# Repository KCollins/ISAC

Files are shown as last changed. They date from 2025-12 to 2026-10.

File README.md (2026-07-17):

# ISAC
The In-Situ Autonomous Column (ISAC) is a low-cost drifter and sensor platform designed to characterize sinking particles in the surface of aquatic environments.

### [**Click here to read the documentation page.**](https://kcollins.github.io/ISAC)

ISAC is both an observational instrument and an experimental instrument. The ISAC drifter monitors the sinking of particulate matter (e.g., volcanic ash, biological cells/aggregates) through the surface. Passive sensing of the sinking particle field (by backscatter and chlorophyll-a fluorescence optical sensors) and active sampling of seawater for biogeochemical variables allows users of ISAC to test the effects of nutrient supply on phytoplankton populations, survey across biogeochemical gradients (in time and space), experimentally manipulate the particle field, and assess sinking speeds of particulate matter and their contribution to the carbon cycle. These capabilities make ISAC a novel tool for interrogating biogeochemistry in aquatic environments.

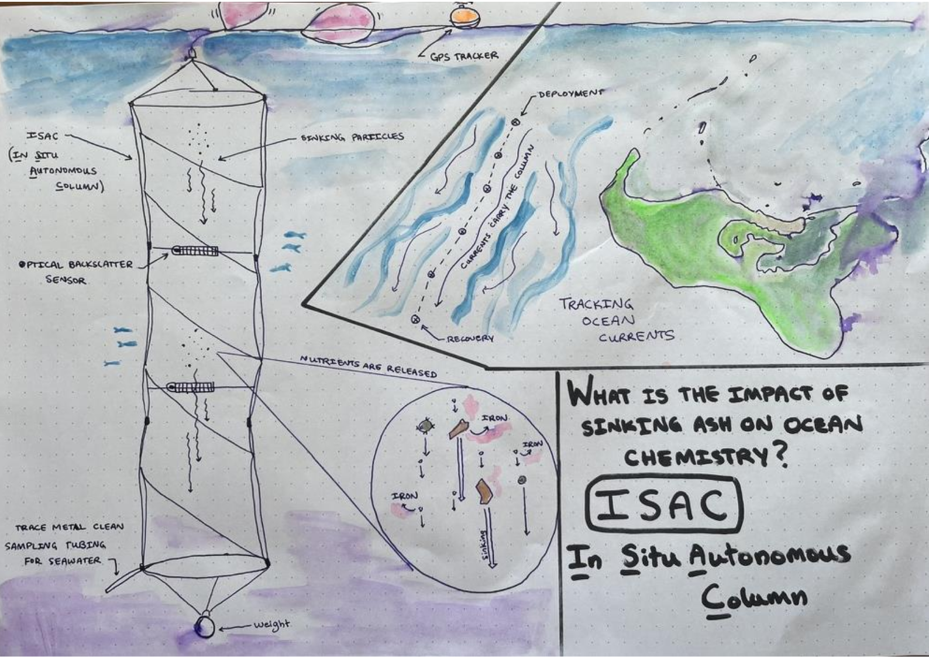
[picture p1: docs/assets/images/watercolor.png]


An initial ISAC prototype was successfully built and deployed in the Western Tropical South Pacific (WTSP) in March 2026. This prototype consists of a nylon column drogue five meters in length, suspended between a float at the top and a weight at the bottom. The column is hand-deployable, has a low above water profile, and drifts with the water parcel. The length of the column is equipped with vertically distributed [Optical Backscatter Sensors (OBS)](https://github.com/tedlanghorst/OpenOBS-328) which monitor sinking particulate matter by logging time series of seawater turbidity over the course of deployment. Ash or other particulate material is deposited manually at the top of the column and observed by the sensors as it settles over the course of 24 hours or more. At the end of the deployment, water samples are pumped from the bottom of the column and the column and sensors are recovered. Initial experiments demonstrated ISAC’s ability to sense ambient and experimental particle fields. Crucially, its ability to sample for trace metal nutrients without contamination was [verified on discrete seawater samples](https://doi.org/10.5281/zenodo.21253933). 

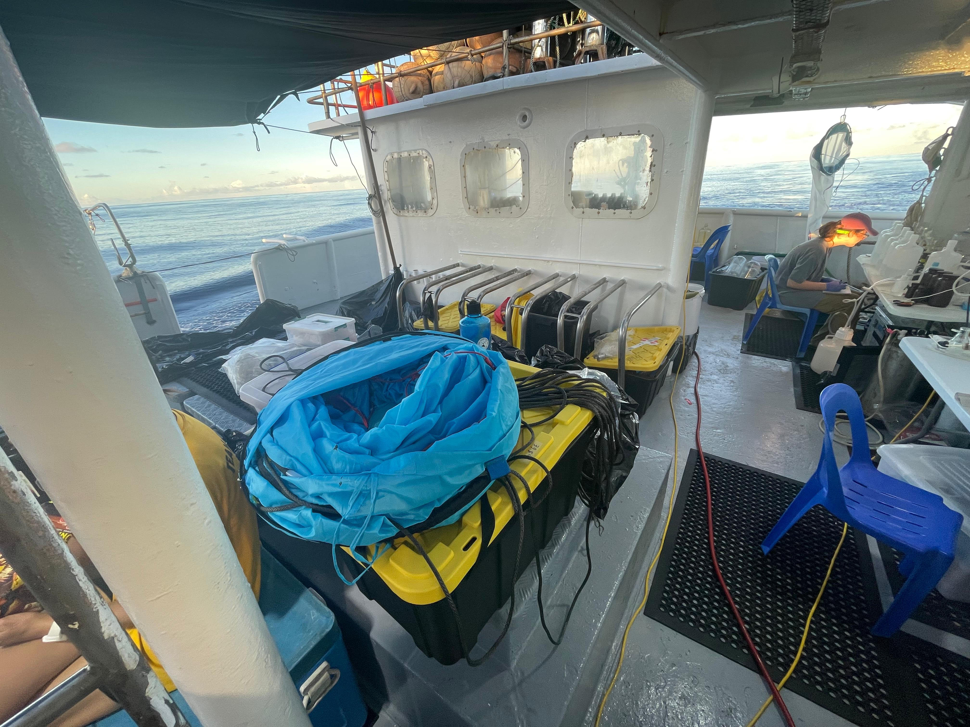
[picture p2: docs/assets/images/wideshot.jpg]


ISAC is also adaptable to a range of other science questions in both lake and marine environments, and closes gaps in the observational system. Moored instrumentation requires routine maintenance and lacks the ability to track moving parcels of water. Uncrewed vehicles require a pilot and shipboard support and skill for deployment and operation. As a water-following device, ISAC is intended to be used where measurements are required to resolve the spatial and temporal evolution of particles and water masses. Proximal to both the ocean and lakes, wildfires are becoming frequent and their impacts on aquatic ecosystems have been understudied. Harmful algae blooms (HABS), which present a challenge for coastal resilience and protection of fisheries, result from an unknown causal chain in changing water chemistry. In response to natural or anthropogenic disturbance events such as volcanic eruptions, wildfires, and HABs, ISAC is an ideal deployable instrument type for mission-oriented experiments and water monitoring. Understanding the fate of particulate matter and its impact on the ecosystem will inform both basic science and the needs of monitoring research and regulatory programs.

### Principal Investigators
 * [Kiefer Forsch](https://orcid.org/0000-0003-1076-164X), University of Southern California
 * [Kristina Collins](https://orcid.org/0000-0002-3816-1948), Space Science Institute

### Manufacturing Collaborators
 * [Ben Kaufman](https://orcid.org/0009-0005-3339-7686): 3D printing, design support
 * [Mike Hawley](https://orcid.org/0009-0007-5088-750X): Sewing

### Acknowledgments
Seed funding for this project was provided by [Growing Oceans](www.growingoceans.com). 
<!--
Sewing consultation was provided by [Capital Quilts](https://www.capitalquilts.com). Collaborative opportunities were supported by AGU LANDiNG and [3D Music](https://3dmusic.org/). Our muse is [Oreo the Cat](https://github.com/KCollins/ISAC/blob/main/docs/assets/images/Oreo.jpg). 
!-->

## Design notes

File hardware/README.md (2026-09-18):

This directory contains hardware source files.

### OpenOBS Sensor Heads
These are all designed to use with Adafruit carrier boards. They do not include any spots for a pressure board, since for our application we're only interested in backscatter.
 - **SensorCapV11.stl**: Suitable for the [VCNL4010](https://www.adafruit.com/product/466?srsltid=AU7gw4UTuG5I8HEObkcyDNkkXtAUzCGb80vCChXrD3bDop7IK6JsJFDD), which is the board used (and validated) in Ted Langhorst's original design.
 - **SensorCapV17.stl**: Suitable for the VCNL4020, 4030, 4040.

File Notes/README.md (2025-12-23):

## Design Notes

### Design Requirements
**Materials:** ABS, PLA, polycarbonate. Aluminum, stainless, Ti. Can't use Fe (obviously), copper, brass or bronze. For lines, assume Dyneema.

## Mechanical Design
Initial sketches.




## Electronics and Instrumentation
### OBS Sensor
Current plan: OpenOBS 328. https://github.com/tedlanghorst/OpenOBS-328

### Peristaltic Pump
Looking at this one: https://www.hardware-x.com/article/S2468-0672(20)30024-9/fulltext

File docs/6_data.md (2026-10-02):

---
layout: page
title: Data
permalink: /data/
---

## Table of Contents 
{:.no_toc}
* TOC
{:toc}

## Processing Code
See https://www.github.com/kcollins/ISAC for Jupyter notebooks with processing code. 

## Deployments

| **Cruise** | **Dates** | **Vessel** | **ISAC Version Description** | **Deployment Goals** | **Datasets** | **Analysis** | 
|---|---|---|---|---|---|---|
| PACSUN2603 | March 2026 | [*F/V Pacific Sunrise*](https://vessels.wcpfc.int/vessel/4073)|  Drogue with 2 OpenOBS sensors.  |  Drogue test, initial ash experiment. | |  
| PACSUN2611 |  November 2026  | | Drogue with 5 OpenOBS sensors. | | | | 

## Visualizations
We use [OpenSpace](www.openspaceproject.com) to create integrated ISAC visualizations. Code, instructions and demo videos can be found here: 
<iframe width="700" height="750" src="https://www.youtube.com/embed/Si8AKwayehU?list=PLTvFnCylkeSBzXo7BVH0SzxiXEjGLZG2X" title="ISAC2, ISAC3, Volcano 1" frameborder="0" allow="accelerometer; autoplay; clipboard-write; encrypted-media; gyroscope; picture-in-picture; web-share" referrerpolicy="strict-origin-when-cross-origin" allowfullscreen></iframe>

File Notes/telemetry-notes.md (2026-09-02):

# Telemetry development notes

## Parts 
- Feather M0 w/ 900 MHz LoRa

## Feather setup
 - [X] Install libraries per instructions at https://learn.adafruit.com/adafruit-feather-m0-basic-proto/using-with-arduino-ide
 - [X] Test blink sketch
 - [ ] Test TX and RX sketches

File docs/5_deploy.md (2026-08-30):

---
layout: page
title: Deployment Protocol
permalink: /deploy/
---

## Introduction
{:.no_toc}

This page contains deployment protocols. 

*Like ISAC, this page is a work in progress.*

## Table of Contents 
{:.no_toc}
* TOC
{:toc}

## Packing Checklist
### Tools for Drogue
- [ ] Line (Dyneema recommended)
- [ ] ***(3D printed blocks?)***
### Tools for OBS sensors
- [ ] USB to micro-USB cable
- [ ] USB-A to USB-C cable
- [ ] 3.6V battery in AA form factor, one for each sensor (bring extras)
- [ ] micro SD card, one for each sensor
- [ ] micro SD card reader
- [ ] charger for 3.6V batteries
- [ ] crescent wrench (if using automotive plugs)
- [ ] strap wrench

## Sensor Checklist
- [ ] Remove cap with strap wrench
- [ ] Check battery voltage
- [ ] Connect to computer via USB
- [ ] Program OpenOBS.ino
- [ ] Replace cap, tighten with strap wrench
- [ ] Record sensor ID. column placement, and time

## Drogue Deployment Protocol
### Deployment
Fllowing a recently “pinged” location (lat/lon) of the ISAC instrumentation, the drifter is hand-deployed over the side of the vessel at a nominal 1 knot speed forward. The float is deployed first and using the slow drift forward and drag on the float, the column is extended at the surface and finally, the weight is dropped into the water, which sinks and orients the column vertically.
The position of the device is nominally tracked every 15 minutes over the entire deployment period (up to 24 hrs). 

### Water Sampling
Water sampling is conducted with a diaphragm pump.

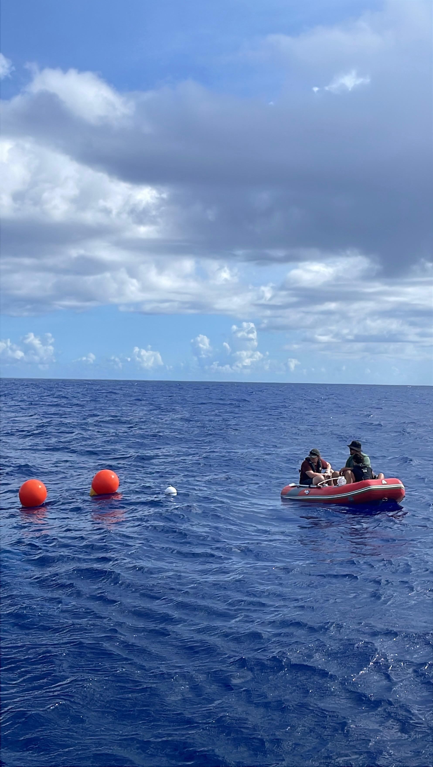
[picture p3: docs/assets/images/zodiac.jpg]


### Recovery
Upon recovery, the vessel must use a grappling hook attached to a line to grab the float and pull it up onto the boat, careful to keep the drifter components away from the side of the vessel. 

---

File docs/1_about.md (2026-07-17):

---
layout: page
title: About
permalink: /about/
mermaid: true
---

The In-Situ Autonomous Column (ISAC) is a low-cost drifter and sensor platform designed to characterize sinking particles in the surface of aquatic environments. 

**ISAC is currently under development.** For a list of deployments to date, see the "Data" page in the menu above.

## About ISAC

The In Situ Autonomous Column (ISAC) is a low-cost system designed to observe sinking ash in seawater. The movement of particulate matter in aquatic ecosystems is intimately tied to the global cycling of carbon and nutrients, and to ecosystem productivity. The fate of particulate matter in the surface (e.g., phytoplankton, ash) is controlled by how quickly it sinks, yet the behavior of these particles is not well-understood, as it is difficult to measure in a natural environment and not possible to reproduce in a lab.  ISAC offers an inexpensive platform for investigating fundamental science questions of particle dynamics and biogeochemical processes under natural oceanographic conditions. 

An initial ISAC prototype was successfully built and deployed in the Western Tropical South Pacific (WTSP) in March 2026. This prototype consists of a nylon column drogue five meters in length, suspended between a float at the top and a weight at the bottom. The column is hand-deployable, has a low above water profile, and drifts with the water parcel. The length of the column is equipped with vertically distributed Optical Backscatter Sensors (OBS) which monitor sinking particulate matter by logging time series of seawater turbidity over the course of deployment. Ash or other particulate material is deposited manually at the top of the column and observed by the sensors as it settles over the course of 24 hours or more. At the end of the deployment, water samples are pumped from the bottom of the column and the column and sensors are recovered. Initial experiments demonstrated ISAC’s ability to sense ambient and experimental particle fields. Crucially, its ability to sample for trace metal nutrients without contamination was [verified on discrete seawater samples](https://doi.org/10.5281/zenodo.21253933). 

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

## Planned Improvements
We are in the process of improving ISAC’s technology readiness level in four domains: structural components, including the drogue column and float; electronic components, including power and telemetry; electromechanical components, including automated ash dispersal and water sampling; and optical sensors, including particle backscatter and chlorophyll-a fluorescence. Since ISAC is a modular system, not every column needs to be equipped with all components; a subset may be selected depending on the science question being addressed. We envision a fully equipped column which will be capable of transmitting position and sensor data in real time, as well as automatically handling the mechanical tasks of water sampling and scattering particulate matter at the top of the column.  

The subsystems we plan to develop are shown in the dependency chart below. 

```mermaid
---
title: ISAC Dependency Graph
---
%%{
  init: {
    'flowchart': {
      'nodeSpacing': 10,
      'rankSpacing': 15,
      'useMaxWidth': false
    }
  }
}%%

flowchart LR
    %% Sensors grouped at the bottom, pointing up to the Drogue
    subgraph Sensors [Environmental Sensors]
        G(Optical Backscatter)
        H(Chlorophyll A)
    end

    %% Core Components
    subgraph Structural [Structural Components]
        A(Column Drogue)
        B(Float)
    end

    subgraph Electronic [Electronic Subsystems]
        C(Power Bus)
        D(Telemetry)
    end

    subgraph Electromechanical [Electromechanical Subsystems]
        E(Automated Water Sampling)
        F(Automated Ash Dispersal)
    end

    %% System Hierarchy and Flow
    %% B-->A
    E -->A
    E --> C
    E --> D
    E --> B

    F --> C
    F --> D

    D --> C
    D --> B
    C --> B

    %% Connecting Sensors to Drogue
    H --> A
    G --> A

    %% %% Invisible structural links to keep layout clean and prevent overlap
    B ~~~ A
    H ~~~ G
    style Structural fill:#dcfce7,stroke:#16a34a,stroke-width:2px
    style Electromechanical fill:#fee2e2,stroke:#dc2626,stroke-width:2px
    style Electronic fill:#ADD8E6,stroke:#0116ff,stroke-width:2px
    %% style Sensors fill:#FFFFED,stroke:#dc2676,stroke-width:2px
```

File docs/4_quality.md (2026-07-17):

---
layout: page
title: Quality, Calibration and Test Procedures
permalink: /testing/
mermaid: true
---

This page concerns quality, calibration and test procedures for subsystems. 
*Like ISAC, this page is a work in progress.*

## OpenOBS Sensors
### QA/QC
Some of the quality issues we encountered with the OpenOBS sensors on our first deployment are reflected in the Ishikawa diagram below. 
```mermaid
ishikawa-beta
    OpenOBS-328 Failures
    Personnel
        Incomplete deployment protocol
    Machines
        Printer settings
        Epoxy protocol
    Materials
        Sensor heads
            Use of PLA (should be using PETG)
        Sensor endcaps
            Automotive cap leaks (should use threaded inserts)
    Methods
        Uneven PVC cuts
            Should brace PVC to ensure even cuts
        Uneven mating of sensor heads
            Should tape around sensor head
    Measurements
        Uncalibrated sensors
    Environment
        Saltwater infiltration     
```

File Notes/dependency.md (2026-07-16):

```mermaid
---
title: ISAC Dependency Graph
---
flowchart LR
    %% Subgraphs
    subgraph Electromechanical [Electromechanical Subsystems]
        E(Automated Water Sampling System)
        F(Automated Ash Dispersal System)
    end

    subgraph Electronic [Electronic Subsystems]
        D(Telemetry System)
        C(Power Bus)
    end

    subgraph Structural [Structural Components]
        B(Float)
        A(Column Drogue)
    end

    subgraph Sensors [Sensors]
        H(Chlorophyll A)
        G(Backscatter)
    end

    %% Bundled Connections
    E --> A & B & C & D
    F --> C & D
    D --> C & B
    C --> B
    G --> A
    H --> D

    %% Color & Border Styles
    style Structural fill:#dcfce7,stroke:#16a34a,stroke-width:2px
    style Electromechanical fill:#fee2e2,stroke:#dc2626,stroke-width:2px
    style Electronic fill:#ADD8E6,stroke:#0116ff,stroke-width:2px
    style Sensors fill:#fffde6,stroke:#FFDB58,stroke-width:2px

    %% Subgraph Title Font Scaling
    style Electromechanical font-size:16px,font-weight:bold
    style Electronic font-size:16px,font-weight:bold
    style Structural font-size:16px,font-weight:bold
    style Sensors font-size:18px,font-weight:bold

    %% Universal Large Font Styling for Nodes
    classDef largeFont font-size:20px,font-weight:bold;
    class A,B,C,D,E,F,G,H largeFont;
```

```mermaid
---
title: ISAC Dependency Graph
---
flowchart LR
    %% Subgraphs
    subgraph Electromechanical [Electromechanical Subsystems]
        E(Automated Water Sampling System)
        F(Automated Ash Dispersal System)
    end

    subgraph Electronic [Electronic Subsystems]
        D(Telemetry System)
        C(Power Bus)
    end

    subgraph Structural [Structural Components]
        B(Float)
        A(Column Drogue)
    end

    subgraph Sensors [Environmental Sensors]
        H(Chlorophyll A)
        G(Backscatter)
    end

    %% Connections
    E --> A
    E --> B
    E --> C
    E --> D

    F --> C
    F --> D

    D --> C
    D --> B
    C --> B

    G --> A
    H --> D

    %% Style Definitions
    style Structural fill:#dcfce7,stroke:#16a34a,stroke-width:2px
    style Electromechanical fill:#fee2e2,stroke:#dc2626,stroke-width:2px
    style Electronic fill:#ADD8E6,stroke:#0116ff,stroke-width:2px
    style Sensors fill:#fffde6,stroke:#FFDB58,stroke-width:2px
```

```mermaid
---
title: ISAC Dependency Graph
---
flowchart LR
    %% Subgraphs
    subgraph Electromechanical [Electromechanical Subsystems]
        E(Automated Water <br>Sampling System)
        F(Automated Ash <br>Dispersal System)
    end

    subgraph Electronic [Electronic Subsystems]
        D(Telemetry System)
        C(Power Bus)
    end

    subgraph Structural [Structural Components]
        B(Float)
        A(Column Drogue)
    end

    subgraph Sensors [Environmental Sensors]
        H(Chlorophyll A)
        G(Backscatter)

    end

    %% --- Streamlined Connections ---
    
    %% Electromechanical Layer
    E --> A
    E --> B
    E --> C
    E --> D

    F --> C
    F --> D

    %% Electronic Layer
    D --> C
    D --> B
    C --> B

    %% Sensors Layer
    G --> A
    H --> D

    %% Style Definitions
    style Structural fill:#dcfce7,stroke:#16a34a,stroke-width:2px
    style Electromechanical fill:#fee2e2,stroke:#dc2626,stroke-width:2px
    style Electronic fill:#ADD8E6,stroke:#0116ff,stroke-width:2px
    style Sensors fill:#fffde6,stroke:#FFDB58,stroke-width:2px
```

```mermaid
---
title: ISAC Dependency Graph
---

flowchart LR
    %% Sensors grouped at the bottom, pointing up to the Drogue
    subgraph Sensors [Environmental Sensors]
        G(Optical Backscatter Sensor)
        H(Chlorophyll A Sensor)
    end

    %% Core Components
    subgraph Structural [Structural Components]
        A(Column Drogue)
        B(Float)
    end

    subgraph Electronic [Electronic Subsystems]
        C(Power Bus)
        D(Telemetry System)
    end

    subgraph Electromechanical [Electromechanical Subsystems]
        E(Automated Water Sampling System)
        F(Automated Ash Dispersal System)
    end

    %% System Hierarchy and Flow
    %% B-->A
    E -->A
    E --> C
    E --> D
    E --> B

    F --> C
    F --> D

    D --> C
    D --> B
    C --> B

    %% Connecting Sensors to Drogue
    H --> A
    G --> A

    %% %% Invisible structural links to keep layout clean and prevent overlap
    B ~~~ A
    G ~~~ Sensors
    style Structural fill:#dcfce7,stroke:#16a34a,stroke-width:2px
    style Electromechanical fill:#fee2e2,stroke:#dc2626,stroke-width:2px
    style Electronic fill:#ADD8E6,stroke:#0116ff,stroke-width:2px
    %% style Sensors fill:#FFFFED,stroke:#dc2676,stroke-width:2px
```

```mermaid
---
title: ISAC Dependency Graph
---
flowchart LR
    %% Subgraphs
    subgraph Electromechanical [Electromechanical Subsystems]
        E(Automated Water <br>Sampling System)
        F(Automated Ash <br>Dispersal System)
    end

    subgraph Electronic [Electronic Subsystems]
        D(Telemetry System)
        C(Power Bus)
    end

    subgraph Structural [Structural Components]
        B(Float)
        A(Column Drogue)
    end

    subgraph Sensors [Environmental Sensors]
        G(Optical <br>Backscatter)
        H(Chlorophyll A)
        I(Optical and Acoustic Sensors)
    end

    %% --- Streamlined Connections ---
    
    %% Electromechanical Layer
    E --> A
    E --> B
    E --> C
    E --> D

    F --> C
    F --> D

    %% Electronic Layer
    D --> C
    D --> B
    C --> B

    %% Sensors Layer
    G --> A
    H --> A
    I-->A

    %% Invisible vertical constraints to stack nodes vertically inside subgraphs
    E ~~~ F
    D ~~~ C
    A ~~~ B
    G ~~~ H

    %% Style Definitions
    style Structural fill:#dcfce7,stroke:#16a34a,stroke-width:2px
    style Electromechanical fill:#fee2e2,stroke:#dc2626,stroke-width:2px
    style Electronic fill:#ADD8E6,stroke:#0116ff,stroke-width:2px
    style Sensors fill:#fffde6,stroke:#FFDB58,stroke-width:2px
```

Compact version:
```mermaid
---
title: ISAC Dependency Graph
---
%%{
  init: {
    'flowchart': {
      'nodeSpacing': 10,
      'rankSpacing': 15,
      'useMaxWidth': false
    }
  }
}%%

flowchart LR
    %% Sensors grouped at the bottom, pointing up to the Drogue
    subgraph Sensors [Environmental Sensors]
        G(Optical Backscatter)
        H(Chlorophyll A)
    end

    %% Core Components
    subgraph Structural [Structural Components]
        A(Column Drogue)
        B(Float)
    end

    subgraph Electronic [Electronic Subsystems]
        C(Power Bus)
        D(Telemetry)
    end

    subgraph Electromechanical [Electromechanical Subsystems]
        E(Automated Water Sampling)
        F(Automated Ash Dispersal)
    end

    %% System Hierarchy and Flow
    %% B-->A
    E -->A
    E --> C
    E --> D
    E --> B

    F --> C
    F --> D

    D --> C
    D --> B
    C --> B

    %% Connecting Sensors to Drogue
    H --> A
    G --> A

    %% %% Invisible structural links to keep layout clean and prevent overlap
    B ~~~ A
    H ~~~ G
    style Structural fill:#dcfce7,stroke:#16a34a,stroke-width:2px
    style Electromechanical fill:#fee2e2,stroke:#dc2626,stroke-width:2px
    style Electronic fill:#ADD8E6,stroke:#0116ff,stroke-width:2px
    %% style Sensors fill:#FFFFED,stroke:#dc2676,stroke-width:2px
```

```mermaid
---
title: ISAC Dependency Graph
---
%%{
  init: {
    'flowchart': {
      'nodeSpacing': 10,
      'rankSpacing': 20,
      'useMaxWidth': false
    }
  }
}%%

flowchart LR
    %% Electromechanical (Left)
    subgraph Electromechanical [Electromechanical Subsystems]
        E(Automated Water Sampling)
        F(Automated Ash Dispersal)
    end

    %% Sensors (Bottom Left/Middle)
    subgraph Sensors [Environmental Sensors]
        G(Modular Sensors)
        H(Integrated Sensors)
    end

    %% Electronic (Middle/Top)
    subgraph Electronic [Electronic Subsystems]
        D(Telemetry)
        C(Power Bus)
    end

    %% Structural (Right)
    subgraph Structural [Structural Components]
        A(Column Drogue)
        B(Float)
    end

    %% System Hierarchy and Flow
    E --> A
    E --> C
    E --> D
    E --> B

    F --> C
    F --> D

    D --> C
    D --> B
    C --> B

    %% Connecting Sensors cleanly
    H --> D
    G --> A

    %% Invisible alignment constraints to keep subgraphs stacked perfectly
    E ~~~ G
    D ~~~ C
    B ~~~ A
    H ~~~ G
    
    %% Styling
    style Structural fill:#dcfce7,stroke:#16a34a,stroke-width:2px
    style Electromechanical fill:#fee2e2,stroke:#dc2626,stroke-width:2px
    style Electronic fill:#ADD8E6,stroke:#0116ff,stroke-width:2px
```

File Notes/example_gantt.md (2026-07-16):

```mermaid
gantt
    title All-Hands Science Timeline
    dateFormat  YYYY-MM-DD

section Natural Variables
    Nitrogen Fixation Annual Cycle: N, 2026-11-01, 150d
    Whale Season: whales, 2026-07-01, 90d

section Meetings and Conferences
    All-Hands Science Discussion: active, milestone, 2026-07-01, 1d
    All-Hands Science Data Forum: milestone, 2026-10-15, 1d
    AGU26, San Francisco: 2026-12-07, 5d

section Field Work
    November cruise (tentative): 2026-11-10, 10d
    January cruise: 2027-01-08, 10d
    March cruise: 2027-03-15, 10d

section Logistics and Milestones
    Thanksgiving 2026: milestone, 2026-11-26, 1d

section ISAC Team
    %% Logistics and Milestones (Include academic calendar and OOF notices; merge these into one logistics section when combining multiple Gantt charts)
        BK OOF: done, bkoof1, 2026-06-01, 5d %% Ben will be in DC.
        KC OOF: done, kcoff1, 2026-07-10, 8d %% Kristina will be in MI.

    %% Telemetry
        Purchase LoRaWAN parts:done, lorabuy, 2026-05-15, 5d
        Verify LoRa bidirectional comms:done, lora_initial_test, 2026-05-15, 2d
        Verify LoRa GPS: lora_gps, 2026-06-01, 15d
        Actuate motor via LoRa:active,  loraactuate, after lora_initial_test, 4d 
        Validate LoRa GPS: lora_gps_test, after lora_gps, 10d

    %% Backscatter Sensors
        Redesign OBS Head: done, obshead, 2026-05-20, 4d
        OBS Board Revision: obsboard, 2026-06-01, 20d
        Build OBS Sensors: obsbuild, after obsboard, 10d

    %% Chla Sensors
        Chla Sensor Selection: done, chlaselect, 2026-05-01, 10d
        Chla Sensor Bench Testing and Programming: active, chla_sensor_test, 2026-05-20, 20d
        Chla Sensor Build: chlabuild, after chla_sensor_test, 30d
        Lake Test for OBS and Chla sensors: laketst, after obsbuild chlabuild, 4d

    %% Ash Dispersal
        Design fixture for ash dispersal: done, fixturedesign, 2026-05-10, 5d
        Ruggedize fixture: ruggedize, 2026-06-05, 3d
        Implement radio control of ash dispersal: radiofixture, after loraactuate ruggedize, 4d
        Identify and order float for ash dispersal system:crit, floatfind, 2026-06-01, 2d
        Build ash dispersal float: floatbuild, after floatfind radiofixture, 7d
        Ash dispersal system pool test: ashpool, after floatbuild, 1d

    %% ISAC Column Build and Test
        Buy webbing for column: webbing, 2026-06-05, 1d
        Sew duplicate column: sew, after webbing, 2d
        Lake test of column with ash dispersal float: floattest, after ashpool sew, 2d
        Write procedure checklist for sensors: sensorprotocol, after chlabuild obsbuild, 2d
        Write procedure checklist for ISAC deployment: protocol, after floattest, 2d
        Pack and Ship Sensors to CA: sensorship, after laketest sensorprotocol, 15d
        Pack and Ship Ash Dispersal System to CA: ashship, after floattest, 15d

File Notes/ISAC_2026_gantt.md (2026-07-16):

```mermaid
gantt
    title ISAC Timeline
    dateFormat  YYYY-MM-DD

section Natural Variables
    %% Nitrogen Fixation Annual Cycle: N, 2026-11-01, 150d
    Whale Season: whales, 2026-07-01, 90d

section Meetings and Conferences
    All-Hands Science Discussion: active, milestone, 2026-07-01, 1d
    All-Hands Science Data Forum: milestone, 2026-10-15, 1d
    AGU26, San Francisco: 2026-12-07, 5d

section Field Work
    November cruise (tentative): 2026-11-10, 10d
    %% January cruise: 2027-01-08, 10d
    %% March cruise: 2027-03-15, 10d

section Logistics and Milestones
    Thanksgiving 2026: milestone, 2026-11-26, 1d
        BK in DC: done, bkoof1, 2026-06-01, 5d 
        KC in MI: done, kcoff1, 2026-07-10, 8d 

    section Telemetry
        Purchase LoRaWAN parts:done, lorabuy, 2026-05-15, 5d
        Verify LoRa bidirectional comms:done, lora_initial_test, 2026-05-15, 2d
        Verify LoRa GPS: lora_gps, 2026-06-01, 15d
        Actuate motor via LoRa:active,  loraactuate, after lora_initial_test, 4d 
        Validate LoRa GPS: lora_gps_test, after lora_gps, 10d

    section Backscatter Sensors
        Redesign OBS Head: done, obshead, 2026-05-20, 4d
        OBS Board Revision: obsboard, 2026-06-01, 20d
        Build OBS Sensors: obsbuild, after obsboard, 10d

    section Chla Sensors
        Chla Sensor Selection: done, chlaselect, 2026-05-01, 10d
        Chla Sensor Bench Testing and Programming: active, chla_sensor_test, 2026-05-20, 20d
        Chla Sensor Build: chlabuild, after chla_sensor_test, 30d
        Lake Test for OBS and Chla sensors: laketst, after obsbuild chlabuild, 4d

    section Ash Dispersal
        Design fixture for ash dispersal: done, fixturedesign, 2026-05-10, 5d
        Ruggedize fixture: ruggedize, 2026-06-05, 3d
        Implement radio control of ash dispersal: radiofixture, after loraactuate ruggedize, 4d
        Identify and order float for ash dispersal system:active, floatfind, 2026-06-01, 2d
        Build ash dispersal float: floatbuild, after floatfind radiofixture, 7d
        Ash dispersal system pool test: ashpool, after floatbuild, 1d

    section ISAC Column Build and Test
        Buy webbing for column: webbing, 2026-06-05, 1d
        Sew duplicate column: sew, after webbing, 2d
        Lake test of column with ash dispersal float: floattest, after ashpool sew, 2d
        Write procedure checklist for sensors: sensorprotocol, after chlabuild obsbuild, 2d
        Write procedure checklist for ISAC deployment: protocol, after floattest, 2d
        Pack and Ship Sensors to CA: sensorship, after laketest sensorprotocol, 15d
```

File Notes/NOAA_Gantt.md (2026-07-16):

```mermaid

gantt
    title Year 1
    dateFormat  YYYY-MM-DD

section Natural Variables
    Nitrogen Fixation Annual Cycle: N, 2026-11-01, 150d
    Whale Season: whales, 2026-07-01, 90d

section Meetings and Conferences
    All-Hands Science Discussion: active, milestone, 2026-07-01, 1d
    All-Hands Science Data Forum: milestone, 2026-10-15, 1d
    AGU26, San Francisco: 2026-12-07, 5d

section Field Work
    November cruise (tentative): 2026-11-10, 10d
    January cruise: 2027-01-08, 10d
    March cruise: 2027-03-15, 10d

section Publishing and Reports
    Milestone A : milestone, m1, 2026-06-10, 1d
    Milestone B : milestone, sameline m1, 2026-07-12, 1d
    Milestone C : milestone, sameline m1, 2026-09-15, 1d

section Telemetry
        Purchase LoRaWAN parts:done, lorabuy, 2026-05-15, 5d
        Verify LoRa bidirectional comms:done, lora_initial_test, 2026-05-15, 2d
        Verify LoRa GPS: lora_gps, 2026-06-01, 15d
        Actuate motor via LoRa:active,  loraactuate, after lora_initial_test, 4d 
        Validate LoRa GPS: lora_gps_test, after lora_gps, 10d

section Backscatter Sensors
        Redesign OBS Head: done, obshead, 2026-05-20, 4d
        OBS Board Revision: obsboard, 2026-06-01, 20d
        Build OBS Sensors: obsbuild, after obsboard, 10d

section Chla Sensors
        Chla Sensor Selection: done, chlaselect, 2026-05-01, 10d
        Chla Sensor Bench Testing and Programming: active, chla_sensor_test, 2026-05-20, 20d
        Chla Sensor Build: chlabuild, after chla_sensor_test, 30d
        Lake Test for OBS and Chla sensors: laketst, after obsbuild chlabuild, 4d

section Ash Dispersal
        Design fixture for ash dispersal: done, fixturedesign, 2026-05-10, 5d
        Ruggedize fixture: ruggedize, 2026-06-05, 3d
        Implement radio control of ash dispersal: radiofixture, after loraactuate ruggedize, 4d
        Identify and order float for ash dispersal system:crit, floatfind, 2026-06-01, 2d
        Build ash dispersal float: floatbuild, after floatfind radiofixture, 7d
        Ash dispersal system pool test: ashpool, after floatbuild, 1d

section ISAC Column Build and Test
        Buy webbing for column: webbing, 2026-06-05, 1d
        Sew duplicate column: sew, after webbing, 2d
        Lake test of column with ash dispersal float: floattest, after ashpool sew, 2d
        Write procedure checklist for sensors: sensorprotocol, after chlabuild obsbuild, 2d
        Write procedure checklist for ISAC deployment: protocol, after floattest, 2d
        Pack and Ship Sensors to CA: sensorship, after laketest sensorprotocol, 15d
        Pack and Ship Ash Dispersal System to CA: ashship, after floattest, 15d
```
```mermaid
---
displayMode: compact
---
gantt
    dateFormat  YYYY-MM-DD
    axisFormat  %d
    title Compact Mode Example
    Requirements  :a1, 2021-01-11, 4w
    Design  :a2, after a1, 4w
    Development  :a3, after a2, 4w
    Test  :a4, after a3, 4w
    Demo  :crit, a5, after a4, 1d
```

```mermaid
timeline
    title Repeated Events
    Period A : Event 1 : Event 2 : Event 3
    Period B : Event 1 : Event 2
```

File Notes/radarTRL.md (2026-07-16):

```mermaid
---
title: "Readiness Level"
---
radar-beta
 axis test["Overall system"]
  axis col["Column Drogue"], f["Float"], p["Power Bus"], t["Telemetry"]
  axis a["Material Dispersal"], s["Automated Sampling"]
  axis b["Backscatter"]
  axis c["Chla"]
  curve y3["Year 3"]{1, 9, 9, 9, 9, 9, 8, 9, 9}
  curve y2["Year 2"]{1, 8, 5, 8, 6, 5, 6, 7, 1}
  curve y1["Year 1"]{1, 8, 3, 6, 2, 3, 2, 4, 1}
  curve y0["Current RL"]{2, 8, 2, 5, 2, 2, 2, 4, 1}

  max 9
  min 0
```

```mermaid
---
title: "Readiness Level"
---
radar-beta
  axis col["Column Drogue"], t["Telemetry"], b["Backscatter"]
  axis c["Chla"], a["Material Dispersal"], s["Automated Sampling"]
  axis v["Visualization Pipeline"]
  curve y3["Year 3"]{9, 9, 9, 9, 9, 8, 9}
  curve y2["Year 2"]{8, 5, 8, 6, 5, 6,7}
  curve y1["Year 1"]{8, 3, 6, 2, 3, 2,4}
  curve y0["Current RL"]{8, 2, 5, 2, 2, 2,4}

  max 9
  min 0
```



```mermaid
---
title: "Readiness Level"
---
radar-beta
  axis col["Column Drogue"], t["Telemetry"], b["Backscatter"]
  axis c["Chla"], a["Material Dispersal"], s["Automated Sampling"]
  axis v["Visualization Pipeline"]
  curve y3["Year 3"]{9, 9, 9, 9, 9, 8, 9}
  curve y2["Year 2"]{8, 5, 8, 6, 5, 6,7}
  curve y1["Year 1"]{8, 3, 6, 2, 3, 2,4}
  curve y0["Current RL"]{8, 2, 5, 2, 2, 2,4}

  max 9
  min 0
```

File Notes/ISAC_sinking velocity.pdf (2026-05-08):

# ISAC

## Estimating sinking rates of particulate matter Kiefer Forsch

04/28/2026

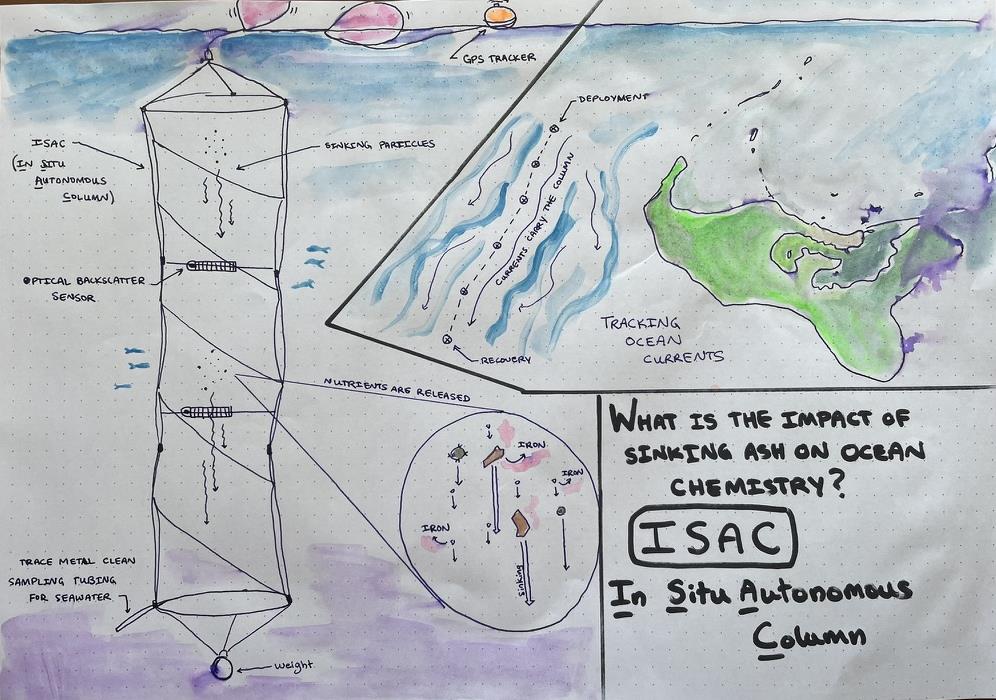
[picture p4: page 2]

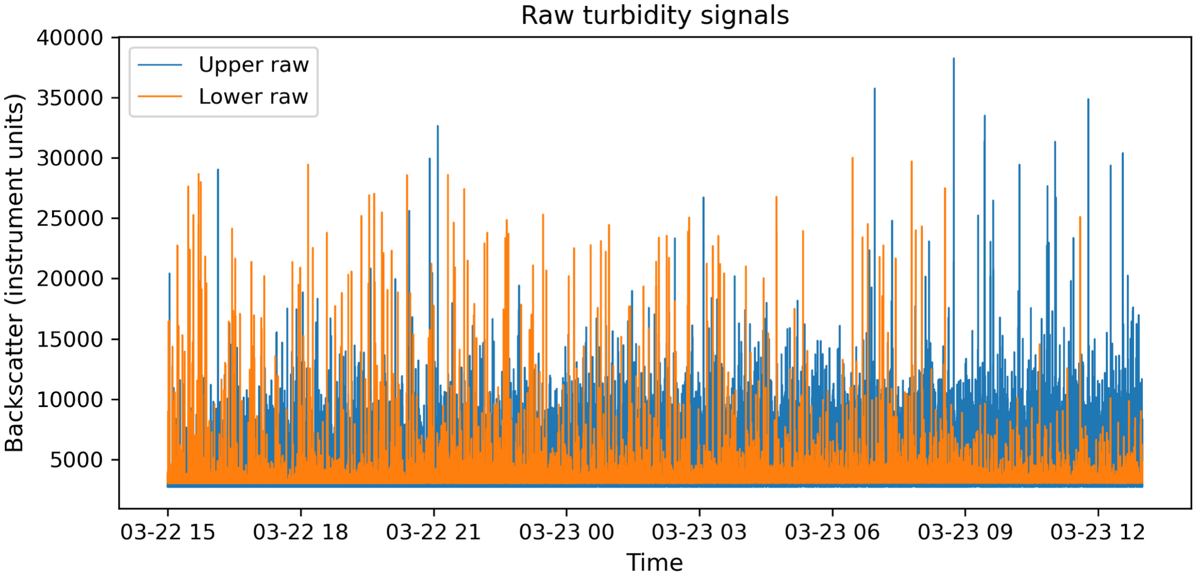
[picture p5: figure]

Distance between sensors: 2.7 m

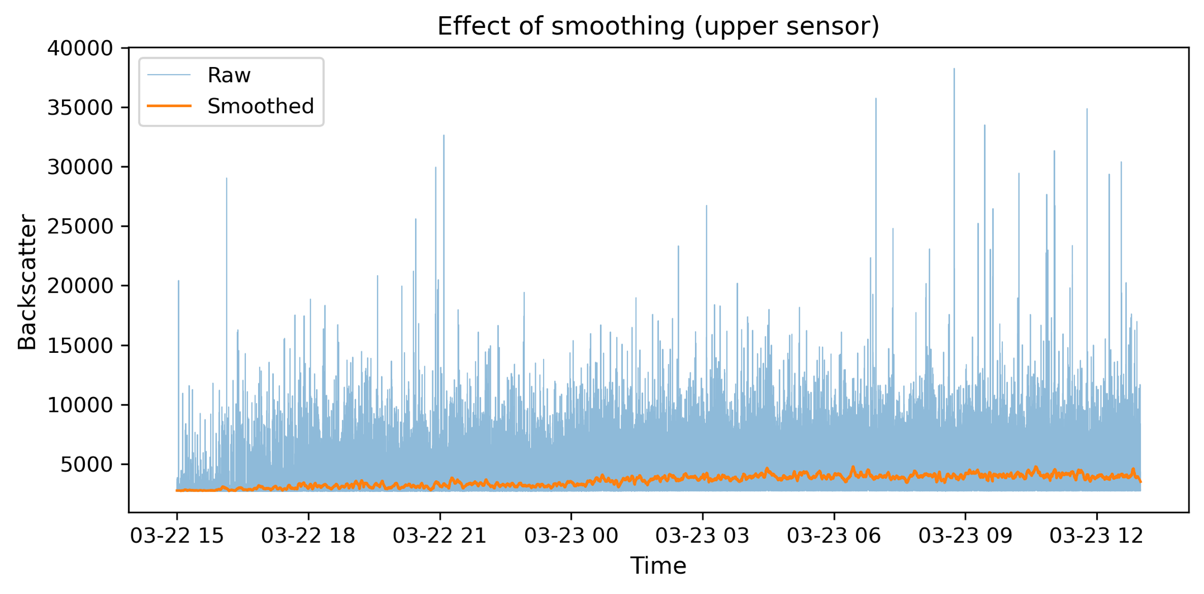
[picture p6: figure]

Uses a Savitzky-Gavol filter over 3 minutes; preserves peak shape (round) and timing, reduces noise

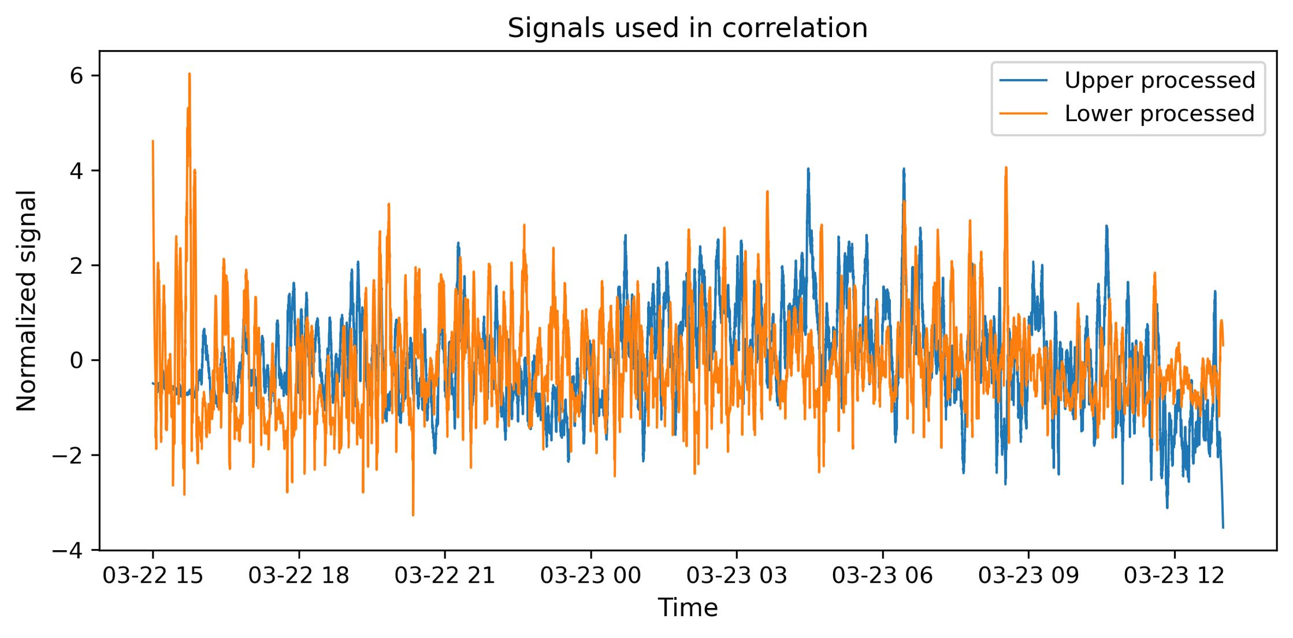
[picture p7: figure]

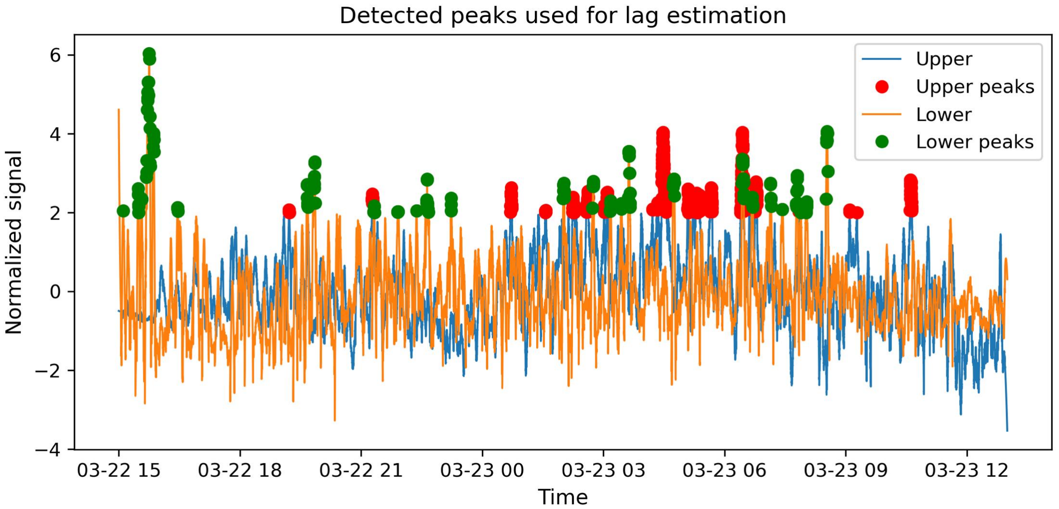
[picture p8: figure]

===== FINAL RESULT =====
Lag: 1.41 hours
Velocity: 46.02 ± 0.28 m/day

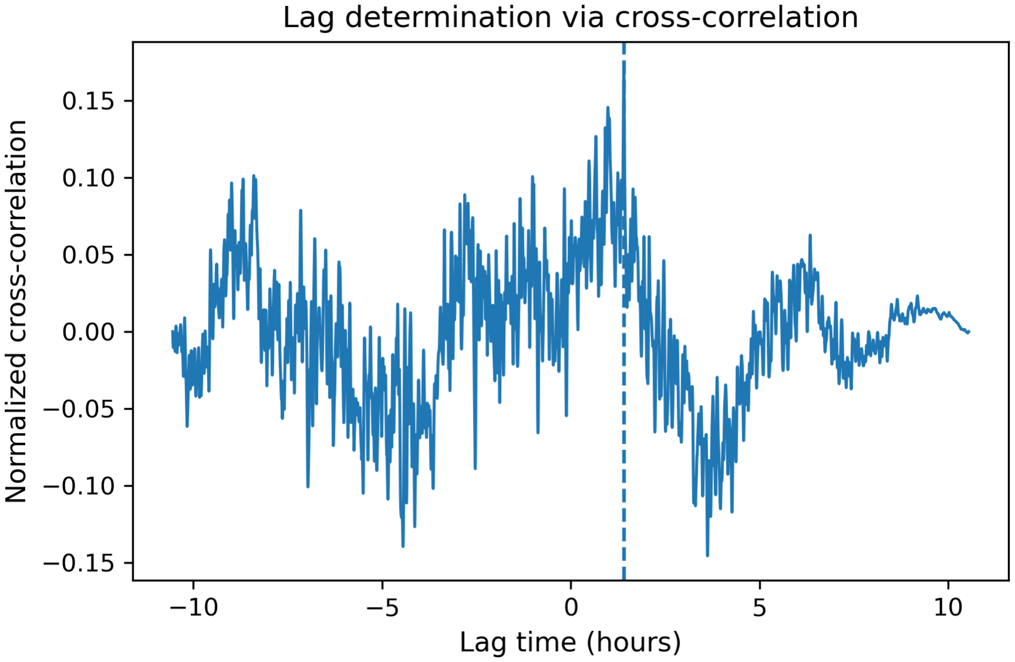
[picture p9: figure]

This result is robust across smoothing intervals.

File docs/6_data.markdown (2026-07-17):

---
layout: page
title: Data
permalink: /data/
---

## Table of Contents 
{:.no_toc}
* TOC
{:toc}

## Processing Code
See https://www.github.com/kcollins/ISAC for Jupyter notebooks with processing code. 

## Deployments
### PACSUN2603
**Vessel:** [*F/V Pacific Sunrise*](https://vessels.wcpfc.int/vessel/4073)

**Dates:** March 2026

**ISAC Version Description:** Drogue with 2 OpenOBS sensors.

**Deployment Goal:** Drogue test, initial ash experiment.

**Data:** 

**Analysis:**

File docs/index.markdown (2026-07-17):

---
# Feel free to add content and custom Front Matter to this file.
# To modify the layout, see https://jekyllrb.com/docs/themes/#overriding-theme-defaults

layout: home
permalink: 
---

Welcome to the ISAC documentation site! Browse the pages linked in the header for information about the project, how to build your own, and where we have deployed and tested our prototypes to date.

If you find an error or have a problem with any part of the project, please let us know by [**opening a new issue**](https://github.com/kcollins/ISAC/issues/new). This leaves a public record of outstanding issues and solutions that can help others. 



---
&nbsp; 

<!-- OpenOBS is published under the [GNU GPL v3 license](https://www.gnu.org/licenses/gpl-3.0.en.html). In short, this license ensures the freedom of use and distribution of this project forever. You can copy this work exactly or modify it (maybe replace the image of my dog with yours), give it away or sell it; what you cannot do is redistribute the OpenOBS, or a derivative of it, without these same freedoms. -->

<!--https://docs.github.com/en/pages/setting-up-a-github-pages-site-with-jekyll/testing-your-github-pages-site-locally-with-jekyll-->

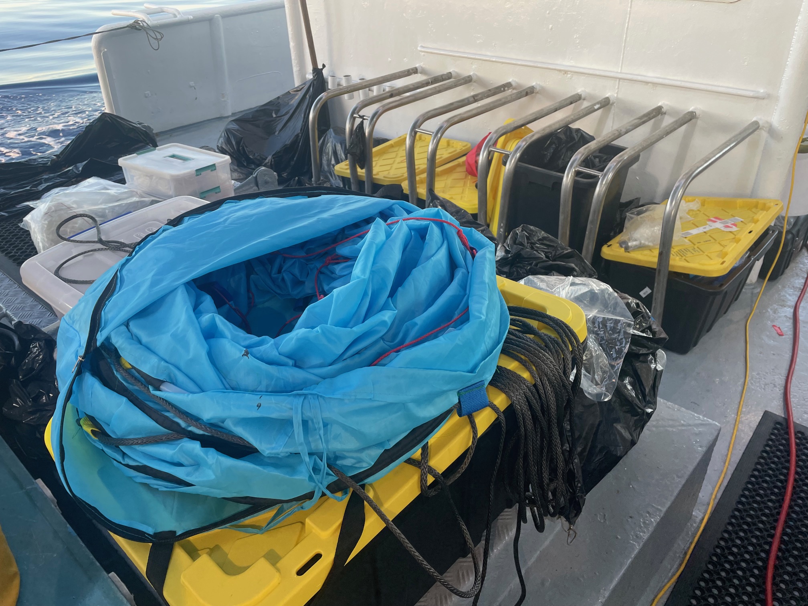
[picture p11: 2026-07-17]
docs/assets/images/ondeck.jpeg

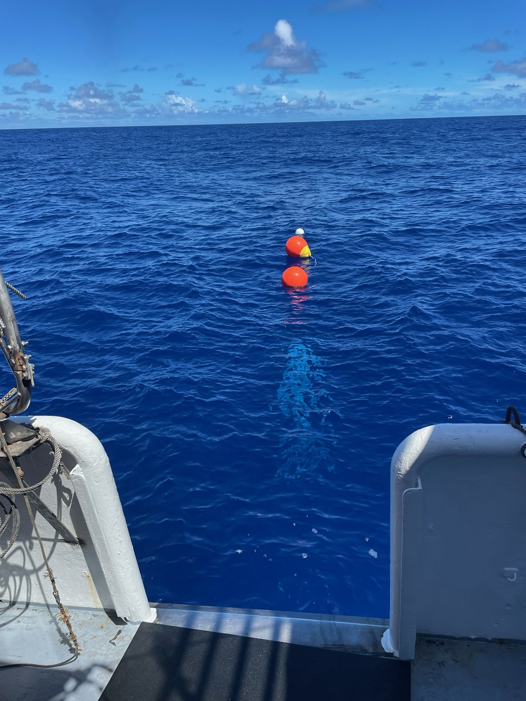
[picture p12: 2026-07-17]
docs/assets/images/ISAC1.jpg

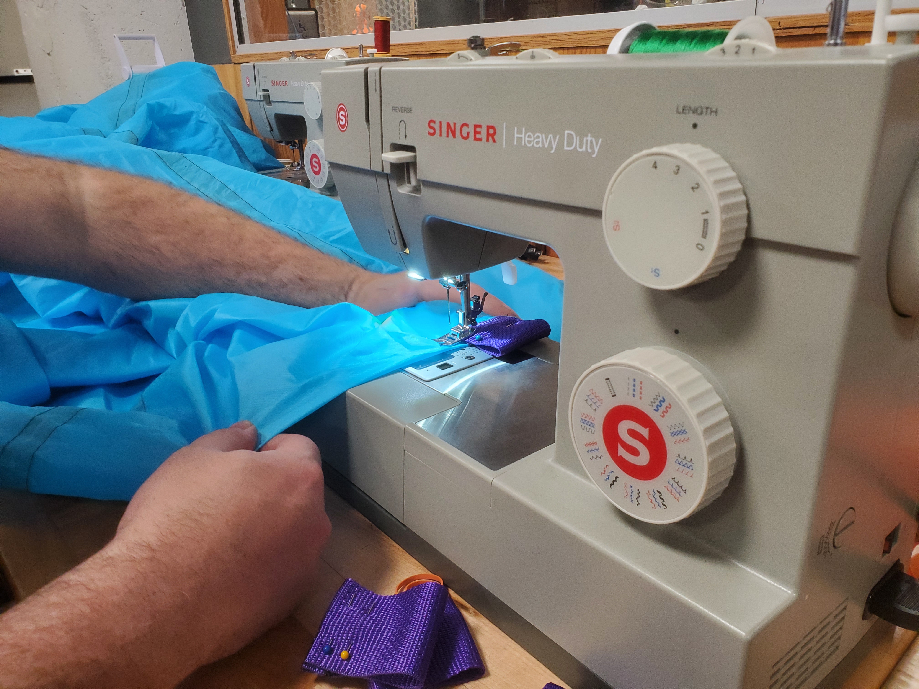
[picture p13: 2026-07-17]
docs/assets/images/sewingmachine.jpg

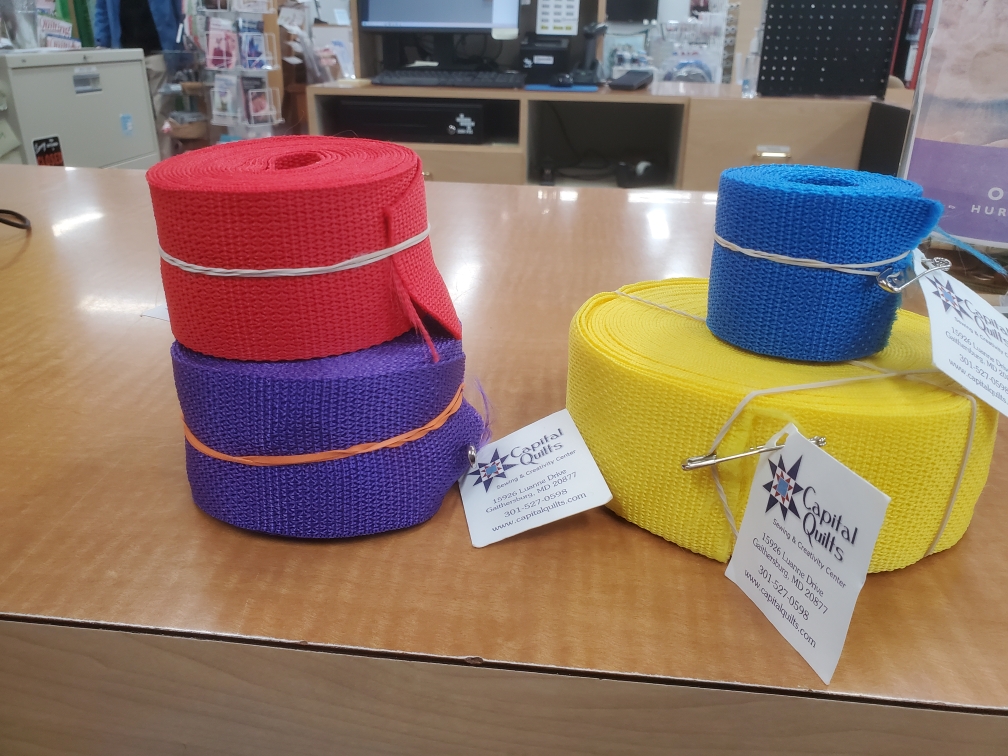
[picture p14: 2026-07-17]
docs/assets/images/webbing.jpeg

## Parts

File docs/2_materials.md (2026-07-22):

---
layout: page
title: Materials
permalink: /materials/
---
## Introduction
{:.no_toc}
The parts cost of ISAC varies based on how many modules you're installing. This documentation is a work in progress. Most of these tools can be found at makerspaces. We conducted much of this build at [think[box]](https://thinkbox.case.edu) at CWRU.

## Table of Contents 
{:.no_toc}
* TOC
{:toc}

## Tools & Materials

### Drogue
* [Sewing machine](https://case.edu/thinkbox/equipment/other-equipment/sewing-machine) 
* Scissors
* Sharpie (black)
* Large area for layout
* Lighter

### Sensors and Electronics
* Soldering iron
* Solder
* Hot air gun/station for electronics. (sometimes called rework station)
* No clean solder paste
* Vacuum pump
* Vacuum chamber (Recommended: [Vevor 3 gallon](https://www.vevor.com/vacuum-pump-c_11109/vevor-3-gallon-vacuum-chamber-with-pump-3-5-cfm-single-stage-vacuum-pump-stainless-steel-degassing-chamber-kit-with-tempere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))
* disposable pipettes (3 mL size works well)
* Hot glue gun
* 3D printer
* PVC pipe cutter (can use a saw)
* PVC cement/solvent
* Electronics tweezers
* Fine flush cutters
* Wire strippers (22-30 AWG)
* Electrical tape (for color-coding, need all 9 colors)
* micro USB cable
* Arduino Nano (or clone; [for ISP programmer](./3_build.markdown#isp-programmer))
* Pogo pins (6 individual or 2x3 grid)

## Parts

### Drogue
* [Dog agility tunnel](https://www.amazon.com/HDP-Agility-Training-Open-Tunnel/dp/B0046HWA4W)
* Nylon webbing (color-coding is advised, per assembly instructions)
* Polyester Thread

### OpenOBS-328 Optical Backscatter Sensors
See the [OpenOBS-328 documentation page](https://tedlanghorst.github.io/OpenOBS-328/) for complete information.

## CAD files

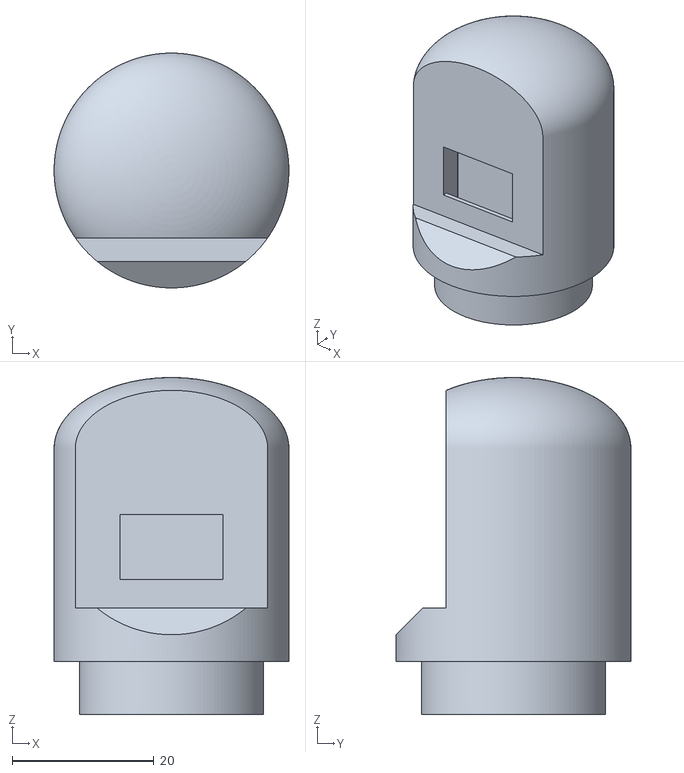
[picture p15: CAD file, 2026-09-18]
hardware/SensorCapV17.stl
33.1 x 33.1 x 47.5

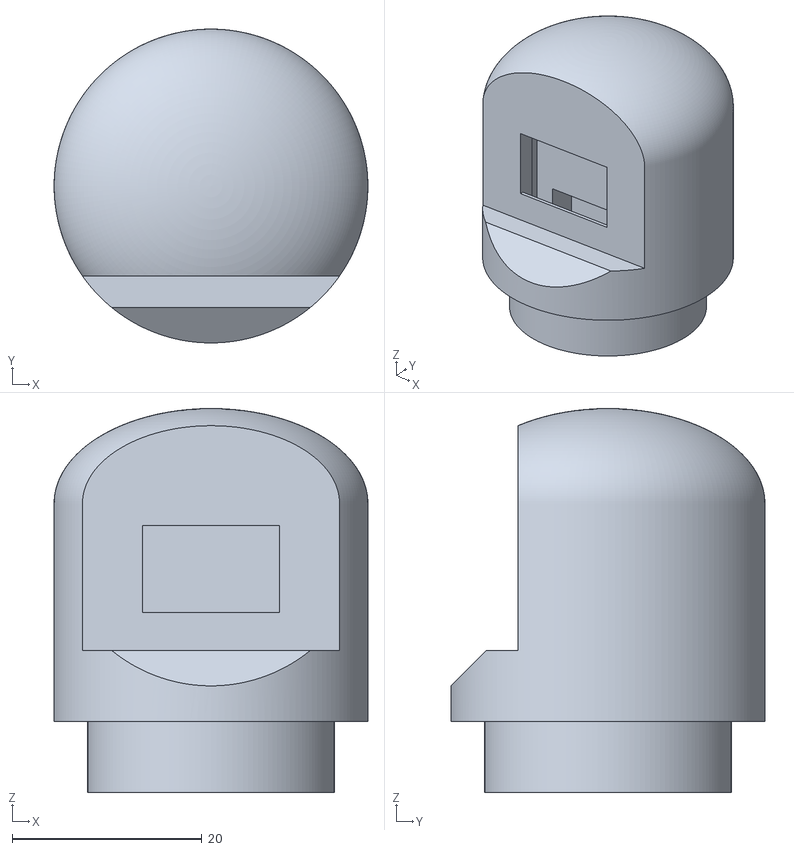
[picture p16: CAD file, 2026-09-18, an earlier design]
hardware/SensorCapV11.stl
33.1 x 33.1 x 40.5

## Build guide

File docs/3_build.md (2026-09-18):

---
layout: page
title: Build
permalink: /build/
---
## Introduction
{:.no_toc}
This guide covers build steps for component parts

## Table of Contents 
{:.no_toc}
* TOC
{:toc}

## Drogue Assembly

### Prepare Tunnel
As the basis for our drogue, we used a [dog agility tunnel](https://www.amazon.com/HDP-Agility-Training-Open-Tunnel/dp/B0046HWA4W) made of nylon, about 5m (16.4') in length and 1.83m (72") in circumference. 

* **Keep the tunnel clean:** As you work, make sure to keep the tunnel off the floor, free of paint, dirt and metal particles. If possible, do these steps in an area with large layout/sewing tables that are relatively clean. 

* **Remove springs:** The dog agility tunnel is held up by metal springs. To remove these, cut the seam at the end and feed the spring out. (There are generally two springs held together with a plastic clip in the middle.) This operation is best accomplished with two people. **Wear safety glasses** and be mindful of stored energy in the springs.

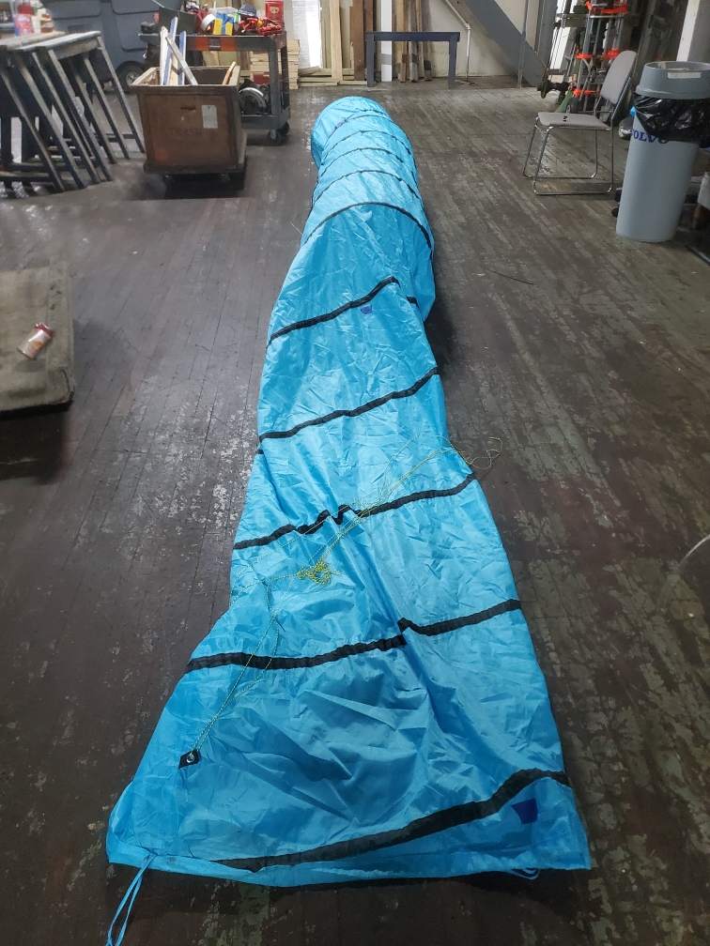
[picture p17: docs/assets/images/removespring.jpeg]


_(**Note:** The floor in this image is **way** too dirty to keep the drogue trace metal clean. This photo is from an early prototyping phase.)_ 

* **Remove grommets:** There are also nylon webbing pieces with metal grommets, which have to be removed since the system is measuring trace metals. Cut these webbing pieces off and singe the ends to prevent fraying.

### Sew tunnel webbing
Nylon webbing loops are assembled as shown below. To prepare a loop, cut 5-7 inches of nylon webbing and singe the edges with a lighter to prevent fraying. Fold and pin both ends of the webbing as shown, with the two pins pointing in the same direction. Fold in half and add a third pin between the two layers, above the fold. The loop can then be sewn to the tunnel using polyester thread.


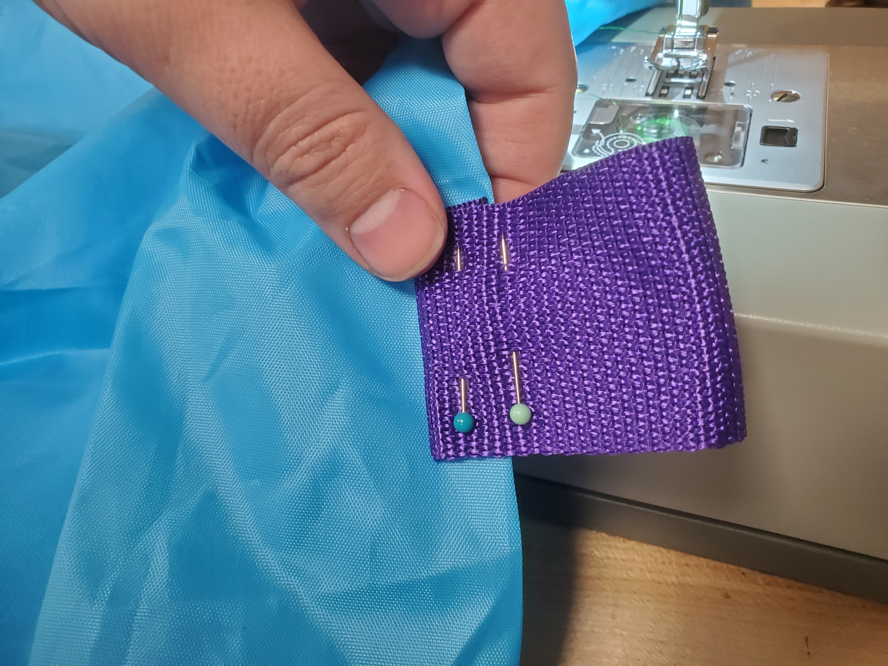
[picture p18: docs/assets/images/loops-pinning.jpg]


Color-coding the loops is advised. We used blue for the ends, red and yellow for three _hoist lines_ of loops 120 degrees apart along the length of the column to which lines can be secured, and purple for _instrument loops_ inside the column to which instrument lines are secured. (They won't be quite even because of manufacturing variation and the positioning of the channel, but that's okay.) The loops on the ends should be sewn perpendicular to the rim of the drogue, so that multiple columns can be zip-tied together. 
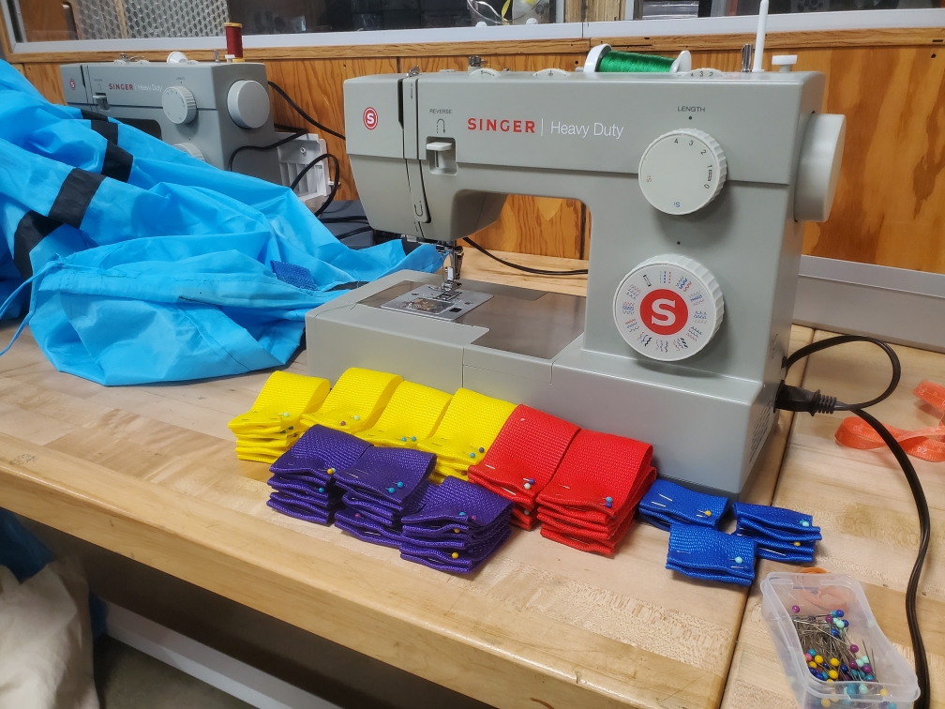
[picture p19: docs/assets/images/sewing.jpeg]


Once the loops are prepared, mark the locations you want to sew them on with a Sharpie. You want the spacing of the loops to be fairly even, but make sure that you aren't interfering with the channel that was used for the spring (which we will use for tubing).  Sew the loops to the column on a pinch, as shown here.  
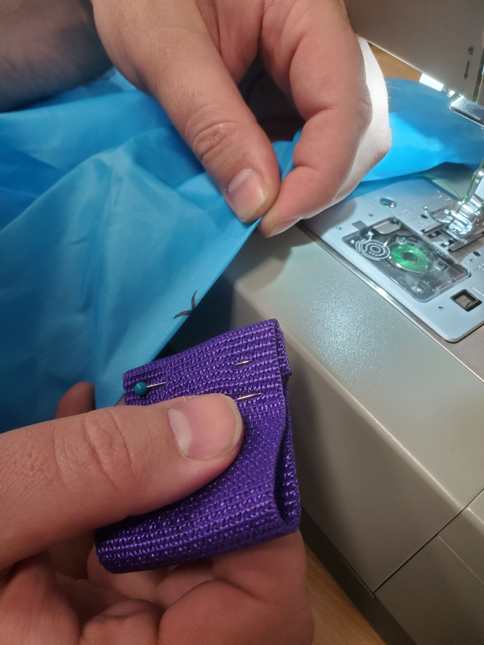
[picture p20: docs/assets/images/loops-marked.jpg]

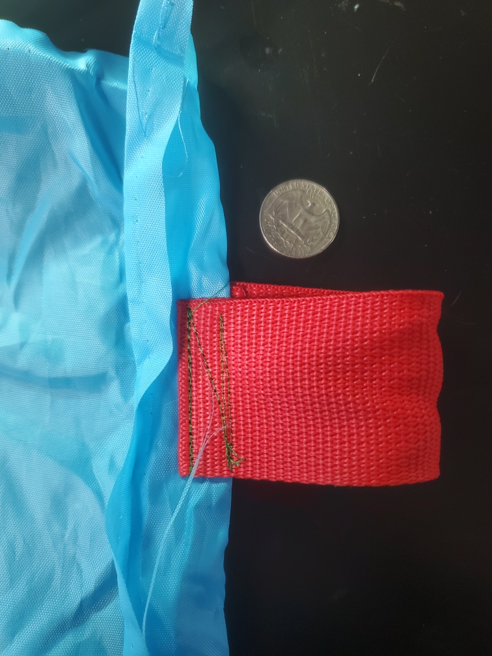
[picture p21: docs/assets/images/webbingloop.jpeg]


Once the loops are added, the drogue can be folded up and placed back in the bag that comes with it. Flag-folding works well.

<!-- ### Rigging (lines, sensors w/ crossref to sensor subsection, spinning - ref 3d printed swivel block), tubing}  -->

### Tubing
1/2 inch HDPE tubing is threaded through the sleeve that formerly contained the spring.

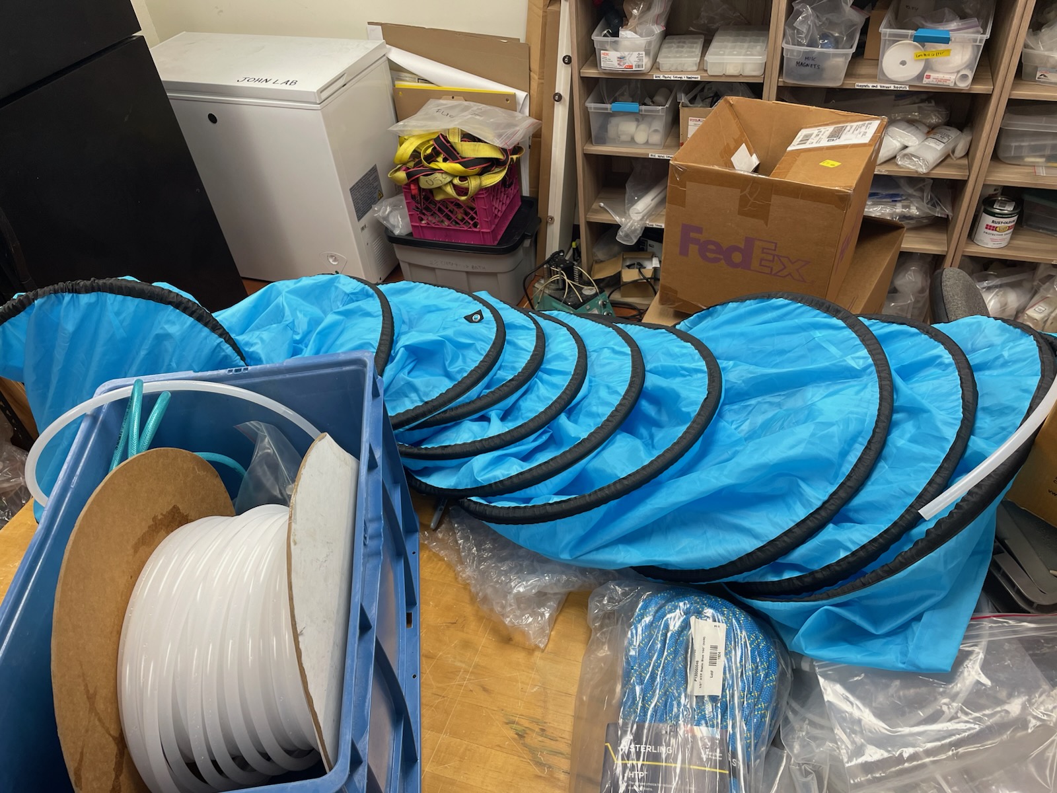
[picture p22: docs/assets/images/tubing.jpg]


## Sensors
### OpenOBS-328 Assembly
See the [OpenOBS-328 documentation page](https://tedlanghorst.github.io/OpenOBS-328/) for general information on constructing the OpenOBS-328 units. Adjustments and notes are discussed below.

* **Sensor head design:** Sensor heads should be printed in PETG. The OpenOBS-328 is designed and validated with the [VCNL4010](https://cdn-shop.adafruit.com/product-files/466/vcnl4010.pdf), which is now considered deprecated, but we were able to get enough [Adafruit carrier boards](https://www.adafruit.com/product/466?srsltid=AU7gw4XNDA02P71WcM21knHilKXrwljO19kkNDAFOyVrtqp8HpFlZwPN) for a couple of rounds. Use [this sensor head](../hardware/SensorCapV11.stl) for the 4010 carrier board, or [this one](../hardware/SensorCapV17.stl) for later boards (the VCNL4020, 4030, 4040 and 4200 all use the same form factor).

> [!Warning]
> At the time of writing, Adafruit is no longer carrying the VCNL4010 boards. We're working on validating later sensors in the series as a replacement. You can read more [here](https://github.com/tedlanghorst/OpenOBS-328/issues/10).

* **Color-coding:** The logger boards are serialized, with 3-digit serial numbers encoded in EEPROM and physically written on the boards. To make the sensors easy to identify just by looking at the housing, we used colored electrical tape and encoded these serial numbers using the [5-band resistor color code,](https://neurophysics.ucsd.edu/courses/physics_120/resistorcharts.pdf), with the tolerance band used to denote different sensor types (VCNL4010 vs VCNL4040, e.g.).

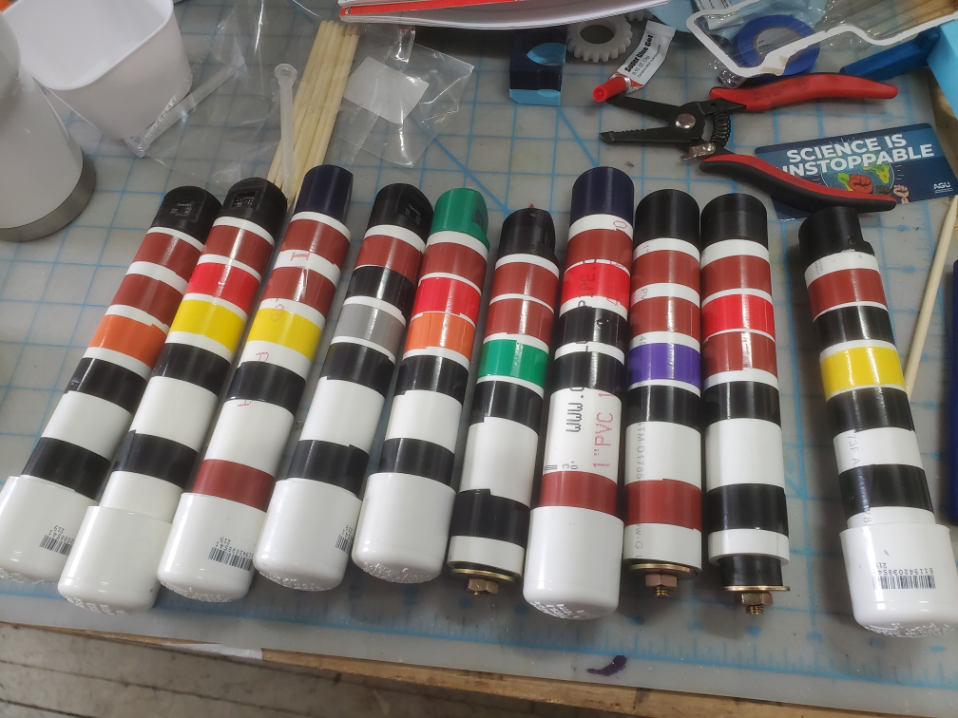
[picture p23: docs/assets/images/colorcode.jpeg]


* **Modified endcaps:** The endcaps in the original design use automotive plugs. An alterative approach is to replace these with threaded inserts, which are tightened using a strap wrench.

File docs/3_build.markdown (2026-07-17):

---
layout: page
title: Build
permalink: /build/
---
## Introduction
{:.no_toc}
This guide covers build steps for component parts

## Table of Contents 
{:.no_toc}
* TOC
{:toc}

## Drogue Assembly

### Prepare Tunnel
* **Remove springs:** The dog agility tunnel is held up by metal springs. To remove these, cut the seam at the end and feed the spring out. (There are generally two springs held together with a plastic clip in the middle.) This operation is best accomplished with two people. **Wear safety glasses** and be mindful of stored energy in the springs.



* **Remove grommets:** There are also nylon webbing pieces with metal grommets, which have to be removed since the system is measuring trace metals. Cut these webbing pieces off and singe the ends to 

### Sew tunnel webbing
Nylon webbing loops are assembled as shown below. To prepare a loop, cut 5-7 inches of nylon webbing and singe the edges with a lighter to prevent fraying. Fold and pin both ends of the webbing as shown, with the two pins pointing in the same direction. Fold in half and add a third pin between the two layers, above the fold. The loop can then be sewn to the tunnel using polyester thread.





Color-coding the loops is advised.



Once the loops are added, the drogue can be folded up and placed back in the bag that comes with it. Flag-folding works well.

<!-- ### Rigging (lines, sensors w/ crossref to sensor subsection, spinning - ref 3d printed swivel block), tubing}  -->

### Tubing
1/2 inch HDPE tubing is threaded through the sleeve that formerly contained the spring.



## Sensors
### OpenOBS-328 Assembly
See the [OpenOBS-328 documentation page](https://tedlanghorst.github.io/OpenOBS-328/) for general information on constructing the OpenOBS-328 units.

* **Color-coding:** The logger boards are serialized, with 3-digit serial numbers encoded in EEPROM and physically written on the boards. To make the sensors easy to identify just by looking at the housing, we used colored electrical tape and encoded these serial numbers using the [5-band resistor color code,](https://neurophysics.ucsd.edu/courses/physics_120/resistorcharts.pdf), with the tolerance band used to denote different 



* **Modified endcaps:** The endcaps in the original design use automotive plugs. An alterative approach is to replace these with threaded inserts, which are tightened using a strap wrench.

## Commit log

2026-04-11 UGH it was in Pacific Time
    data handling notebook is pretty solid, should still fix up the X-axis labels on the time domain plots
2026-04-11 General cleanup
    Data notebook is much better now, and creates two versions of each experiment log: one which includes all the data from the sensors (X_full.csv) and one which only includes the data between the recor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
2026-06-07 Update radarTRL.md
    Added a current/year zero curve. (We should probably talk through the goal RLs for each year.)
2026-09-18 4010 sensor cap
    Default cap for the 4010 sensor
    [SensorCapV11.stl]
2026-09-18 4040 Sesnor head
    Default cap for the 4040 sensor
    [SensorCapV17.stl]
2026-09-18 Update README.md
    Added documentation of the new sensor heads Ben uploaded.
2026-09-18 Update 3_build.md
    Added information on sensor heads.
2026-10-07 Add files via upload
    Added head designs for the 4010 and 4030 sensors in PETG on a Creative Evo (your results may vary)
2026-10-10 Create OpenOBS_4030.ino
    An Arduino sketch that works with the html page in this folder.
2026-10-10 Add files via upload
    HTML page for synchronizing, checking logs and starting sensors up.
2026-10-13 Python code for plotting data from multiple sensors, and some example files.
2026-10-19 Sample data files.
2026-10-20 Create OBS_list.html
    HTML page to track sensor status.
2026-10-20 Create sensors.csv
    Dummy file to check new HTML page.
2026-10-20 Update sensors.csv
    Updated with data.
2026-10-20 Update sensors.csv
    Added commas, trying to get preview to work
2026-10-20 Update OBS_list.html
    Dynamic filtering
2026-10-20 Update sensors.csv
    Correcting location and adding info for 150
2026-10-20 Update OBS_list.html
    Fixed filtering by status.
2026-10-20 Update sensors.csv
    Corrected status from "working" to "building" for several sensors I haven't finished with yet.
2026-10-20 Update OBS_Reader.ipynb
    Added datetime filtering, function to read metadata/header comments.
2026-10-20 Update OBS.html
    First pass at adding metadata and cadence/current setting.
2026-10-20 Update VCNL-universal-logger.ino
    Fixed data gap and added current setting and comment logging.
2026-10-20 Update OBS.html
    Restricts current/cadence settings based on which sensor board is connected.
2026-10-21 Synchronized 4010 test files and messy plotting code to compare power levels.
2026-10-21 Update OBS.html
    Removed IR power options above 140 mA for 4030/4040.
2026-10-21 Update OBS.html
    Changed 4010/20 default label to 200 mA.
2026-10-21 Update VCNL-universal-logger.ino
    Includes header notes, can set current from newest rev of HTML page. Timesync, current settings and multiple sensor types (4010, 20, 30, 40) verified.
2026-10-23 Update sensors.csv
    Added notes about #150.
2026-11-02 Update 5_deploy.md
    Updated link to https://github.com/KCollins/ISAC/blob/main/docs/_data/sensors.csv
